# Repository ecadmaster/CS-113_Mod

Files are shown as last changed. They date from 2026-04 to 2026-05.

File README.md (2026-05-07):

# Modernización del Manipulador Robótico CS-113 / RS-2200 Pro-Arm

Este proyecto tiene como objetivo la recuperación y actualización tecnológica de los brazos robóticos CS-113 (RS-2200 Pro-Arm) pertenecientes a la [Universidad de Los Andes (ULA)](http://ula.ve/). Mediante el estudio del esquema original y la migración a herramientas modernas como [KiCad EDA](https://www.kicad.org/), se ha diseñado un método para interceptar el bus de control original y sustituir el microprocesador [Zilog Z80](https://www.zilog.com/docs/z80/um0080.pdf) por [microcontroladores](https://es.wikipedia.org/wiki/Microcontrolador)/[SoC](https://es.wikipedia.org/wiki/Sistema_en_un_chip) de nueva generación.

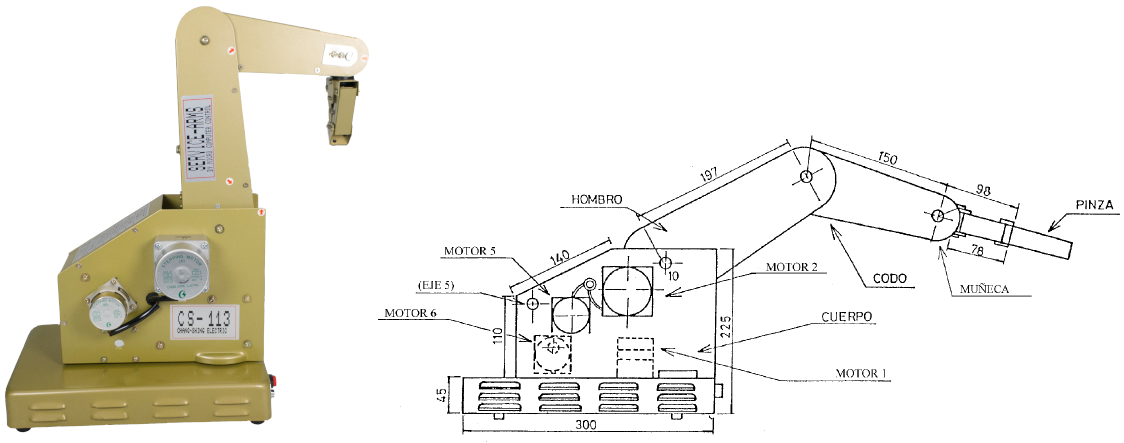
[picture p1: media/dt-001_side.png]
cs-113_side


## Descripción del Proyecto

Los manipuladores robóticos CS-113 fueron equipos estándar en laboratorios de robótica, pero su dependencia del [puerto paralelo (LPT)](https://es.wikipedia.org/wiki/Puerto_paralelo) y del microprocesador Z80 los hace difícilmente integrables en entornos actuales.

Este desarrollo propone:

- Ingeniería Inversa: Estudio del esquema original de la placa rotulada como DT-001.
- Migración CAD: Reconstrucción del esquema en KiCad EDA para facilitar el análisis de interconexiones.
- Intercepción de Bus: Remoción de los [ICs](https://es.wikipedia.org/wiki/Circuito_integrado) [Zilog Z80](https://www.zilog.com/docs/z80/um0080.pdf) ($$C4$$ renombrado como $$uC4$$) y [74LS04](https://www.ti.com/lit/ds/symlink/sn74ls04.pdf) ($$D7$$ renombrado como $$uD7$$) para inyectar señales de control desde un controlador externo.
- Control Moderno: Uso de una tarjeta [MikroElectronika EasyPIC6](https://www.microchip.com/en-us/development-tool/tmik003) actualizada con un microcontrolador [Microchip PIC18F46K40](https://www.microchip.com/en-us/product/pic18f46k40).

## Esquemas

La [placa base](https://es.wikipedia.org/wiki/Circuito_impreso) del manipulador se encuentra ubicada por la parte inferior del mismo.

### Esquema original

El circuito disponible en la pagina #13 del documento [RS-2200_Pro-Arm_Robotics](datasheet/RS-2200_Pro-Arm_Robotics.pdf), entre otros valores interesantes que se logran conseguir allí de éste aparato.

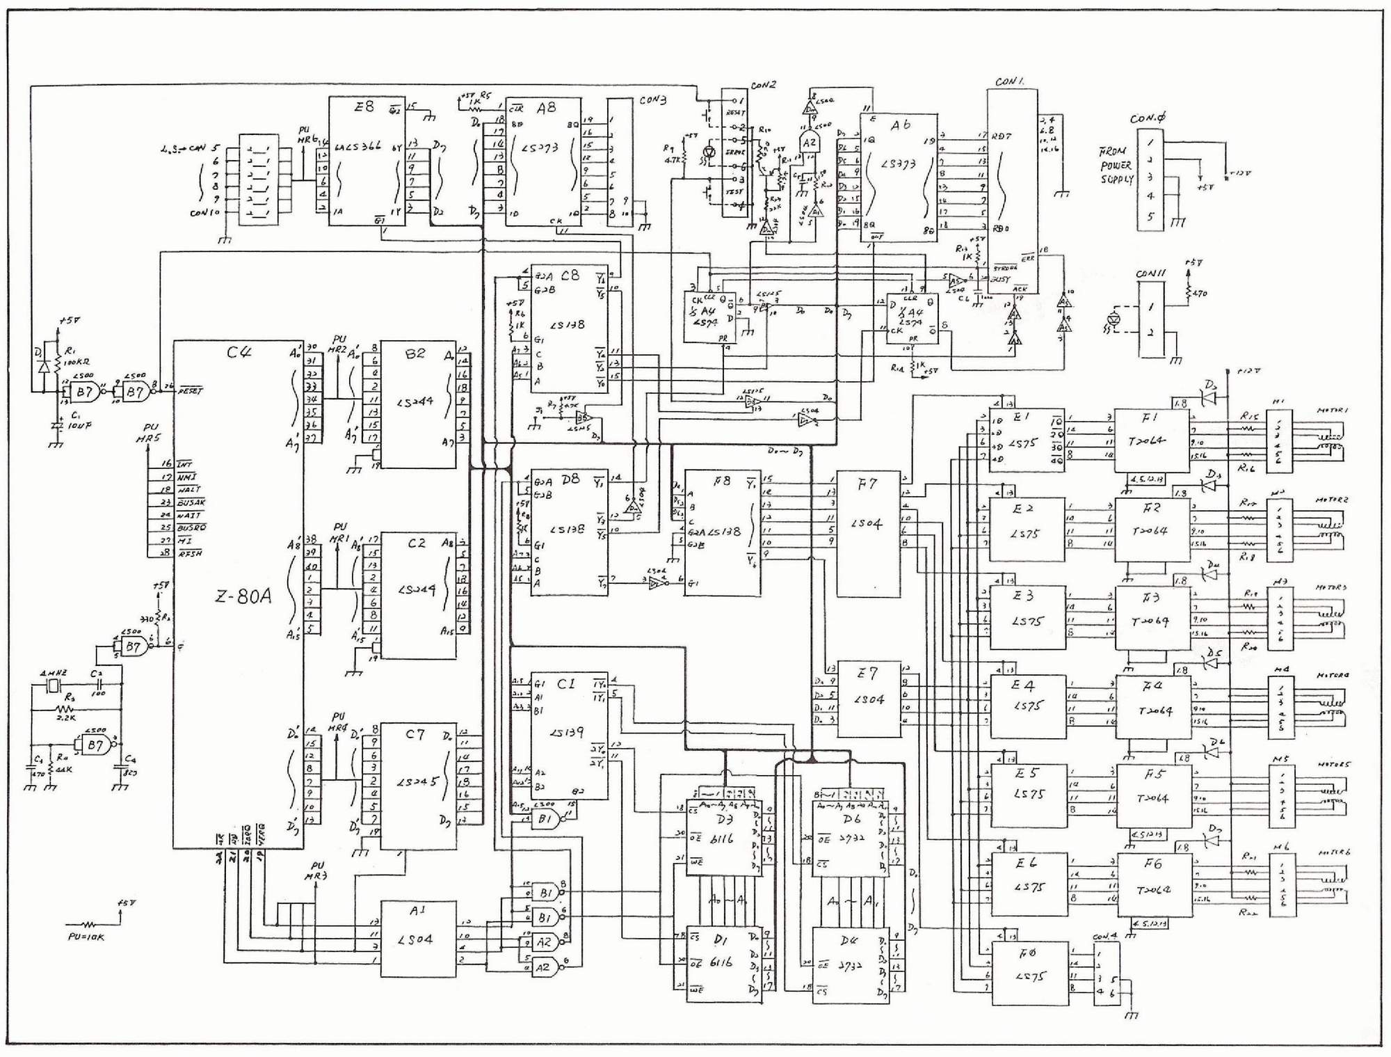
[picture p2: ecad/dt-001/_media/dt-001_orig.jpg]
dt-001-orig


### Esquema migrado a KiCad EDA

El esquema migrado a una herramienta de diseño es como sigue:

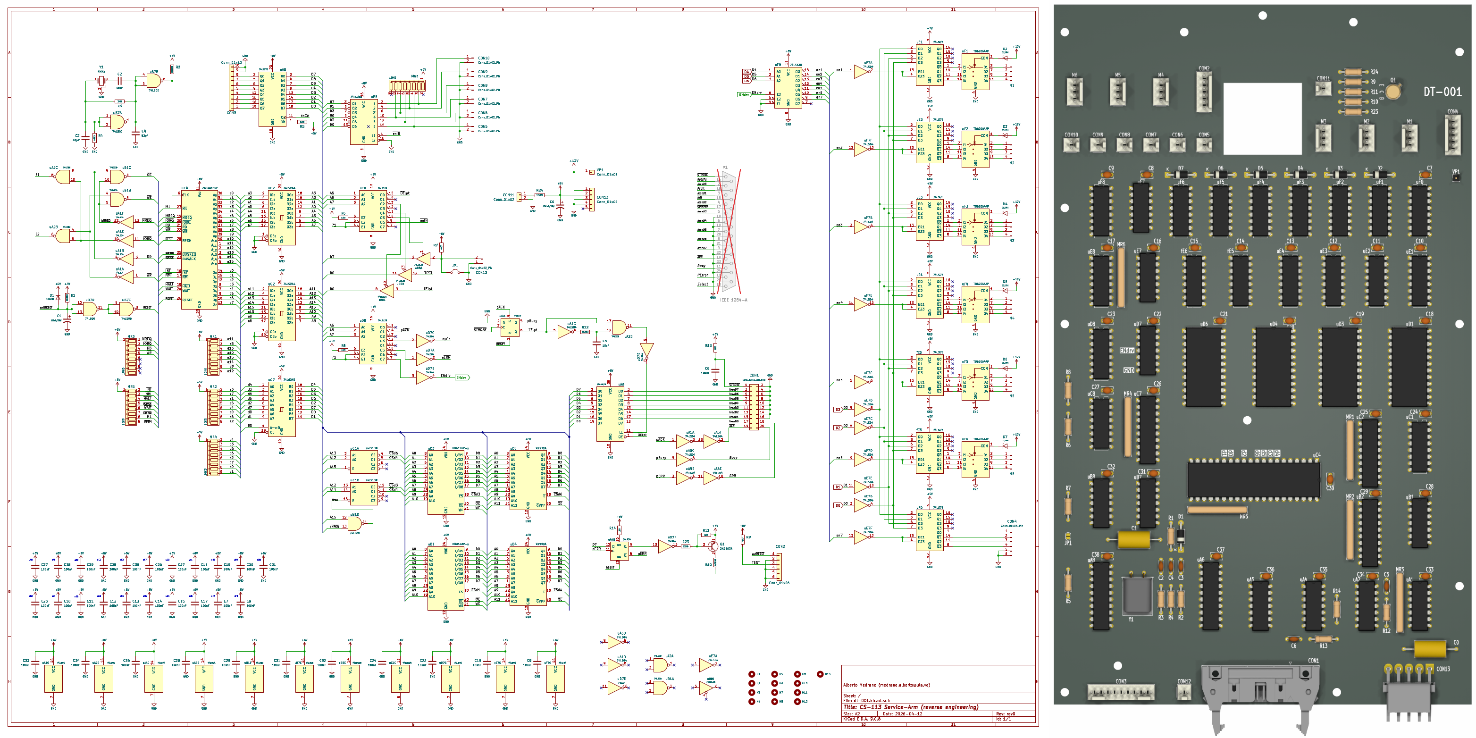
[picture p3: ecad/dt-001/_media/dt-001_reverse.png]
dt-001-kicad-sch


## Hardware y Modificaciones

### Componentes Reutilizados (Bloque de Potencia)

La placa original utiliza una arquitectura lógica robusta que se mantiene para el manejo de los motores, para ello se requiere la comprensión de los siguientes elementos:

- [74LS245](https://www.ti.com/lit/ds/symlink/sn74ls245.pdf): Transceptores de bus octales.
- [74LS138](https://www.ti.com/lit/ds/symlink/sn74ls138.pdf): Decodificador/demultiplexor de 3 a 8 líneas.
- [74LS75](https://www.ti.com/lit/ds/symlink/sn74ls75.pdf): Latches biestables de 4 bits.
- [TD62064AP](https://mm.digikey.com/Volume0/opasdata/d220001/medias/docus/932/TD62064AP%2CAF.pdf): Drivers [Darlington](https://es.wikipedia.org/wiki/Transistor_Darlington) de alta corriente para los [motores paso a paso (Stepper)](https://es.wikipedia.org/wiki/Motor_paso_a_paso) de tipo unipolar.

Una vez consolidado ese estudio y analizando la etapa de potencia, prácticamente solo se requiere el uso de lo siguiente:

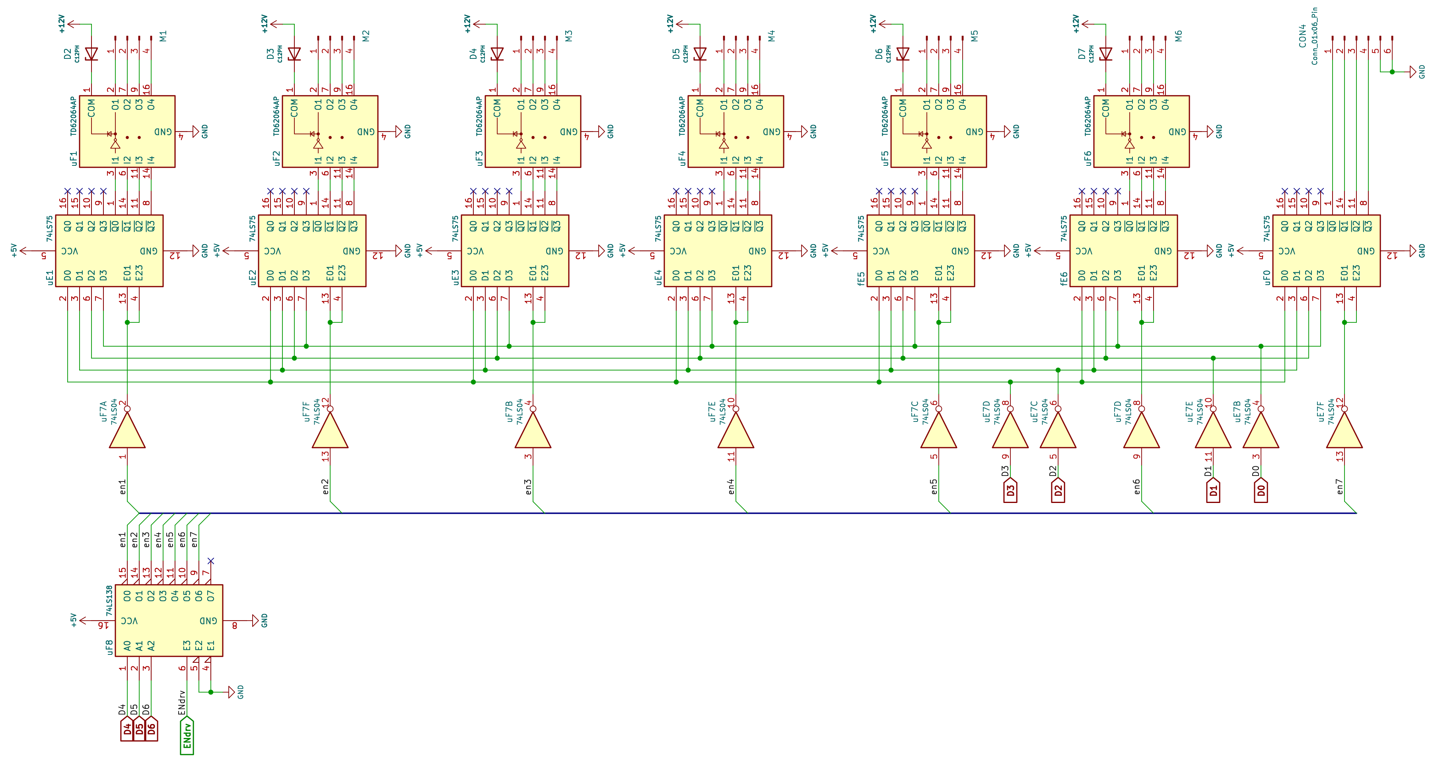
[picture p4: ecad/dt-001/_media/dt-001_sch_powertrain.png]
dt-001_sch_powertrain


Lo anterior sugiere que los IC: $$uC7$$, $$uE1$$, $$uE2$$, $$uE3$$, $$uE4$$, $$uE5$$, $$uE6$$, $$uE7$$, $$uF0$$, $$uF1$$, $$uF2$$, $$uF3$$, $$uF4$$, $$uF5$$, $$uF6$$, $$uF7$$ y $$uF8$$ deban estar debidamente colocados.

Tambien es requerido remover los ICs: $$uA6$$, $$uA8$$, $$uB8$$, $$uC4$$(Z80), $$uD1$$, $$uD3$$, $$uD4$$, $$uD6$$ y $$uD7$$ y $$uD7$$ para no interferir con las señales externas que provengan del controlador externo.

### Interfaz de Conexión (DB9 Personalizado)

Se ha implementado una conexión mediante un conector DB9 macho para el control de los 6 motores de paso y funciones adicionales:

| DB9 Macho | Etiqueta | Conexión |
| :--- | :--- | :--- |
| Pin 1	| d0 | $$uC4$$ pin #14 |
| Pin 2	| d1 | $$uC4$$ pin #15 |
| Pin 3	| d2 | $$uC4$$ pin #12 |
| Pin 4	| d3 | $$uC4$$ pin #8 |
| Pin 5	| d4 | $$uC4$$ pin #7 |
| Pin 6	| d5 | $$uC4$$ pin #9 |
| Pin 7	| d6 | $$uC4$$ pin #10 |
| Pin 8	| ENdrv | $$uD7$$ pin #4 |
| Pin 9	| GND | $$uD7$$ pin #7 |

Quedando la modificación como sigue:

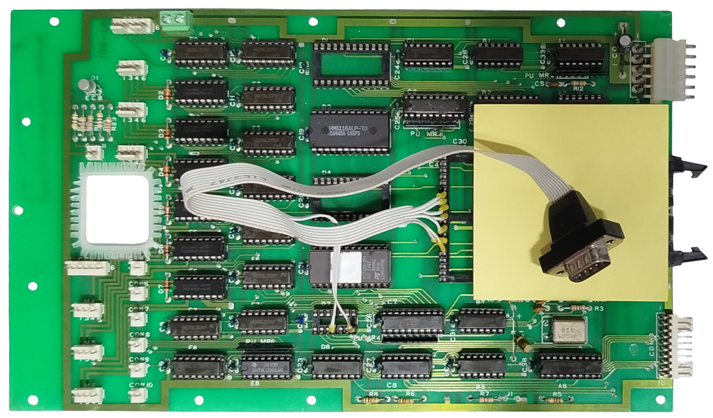
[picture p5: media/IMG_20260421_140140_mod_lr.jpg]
IMG_20260421_140140_mod_lr


Una propuesta de adaptación en la parte trasera es como sigue:

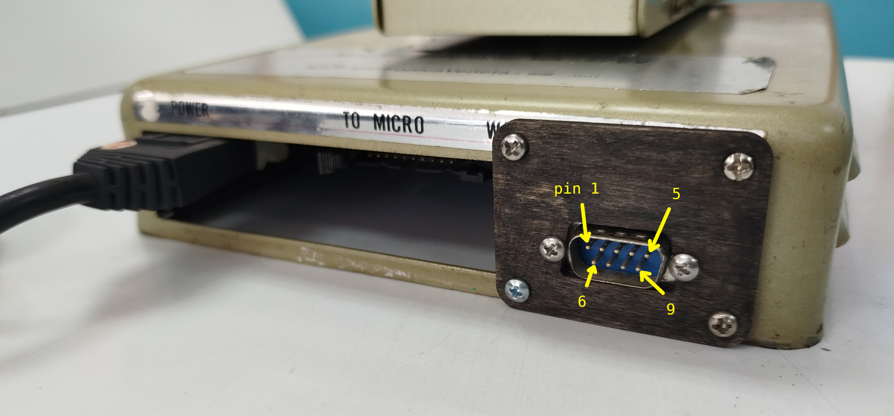
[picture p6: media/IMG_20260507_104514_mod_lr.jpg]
IMG_20260507_104514_mod_lr


El circuito que maneja el tren de potencia funciona con 5V TTL dado que todas las señales son de tipo entrada. Pueden conectarse controladores que funcionen a 3.3V directo sin necesidad de circuitos de interfaz, considere revisar los voltajes admitidos, ver [Logic Guide](https://www.ti.com/lit/sg/sdyu001ab/sdyu001ab.pdf) (de Texas Instruments) para mayor detalle y videoclase [Circuitos Interfaz](https://youtu.be/W1FWi5FtGR8).

## Desarrollo de Software

El firmware actual está siendo desarrollado para el [PIC18F46K40](https://www.microchip.com/en-us/product/pic18f46k40) utilizando:

- [MPLAB X IDE](https://www.microchip.com/en-us/tools-resources/develop/mplab-x-ide) con compilador [XC8](https://www.microchip.com/en-us/tools-resources/develop/mplab-xc-compilers/xc8).
- [MPLAB Code Configurator (MCC)](https://www.microchip.com/en-us/tools-resources/configure/mplab-code-configurator) para la configuración de periféricos.
- Capacidad de operación autónoma, asistida o vía [USB](https://es.wikipedia.org/wiki/Universal_Serial_Bus).

## Enlaces de Interés y Referencias

Proyectos y documentación relacionada que han servido de base:

- [Repositorio Digital ULA, Diseño e implementación de tarjeta de control para un brazo robotico CS-113, que se controle via USB](http://bdigital2.ula.ve:8080/xmlui/handle/654321/11944)
- [Análisis Técnico ITC](https://itc.ktu.lt/index.php/ITC/article/view/985/1054)
- [Hilo en Arduino Forum - Reconstrucción CS-113](https://forum.arduino.cc/t/reconstruccion-de-robot-cs-113/483691)
- [CS-113 Service-Arm](https://openvrg.moodlehub.com/file.php/30/cyr_0204/cyr_01/robotica/cs113.htm)
- [Hackaday.io - Robot Arm CS-113 Project](https://hackaday.io/project/168093-robot-arm-cs-113-18f4550-pic-usb-pc-controller)

Nota: Si has realizado algún intento de desarrollo con este manipulador, te invitamos a colaborar agregando tu referencia en esta sección.

## Colaboradores
- [Alberto Medrano](https://github.com/ecadmaster/)
- Francisco Viloria
- Gerardo Rueda
- Luis Araujo

## Instalación y Uso

Clona el repositorio:

```git clone https://github.com/ecadmaster/CS-113_Mod.git```

Consulta las datasheets para entender los límites operativos de los integrados.

## Contribuciones y Licencia
Este proyecto está bajo la licencia MIT. Las sugerencias de mejora para el entorno académico de la Escuela de Ingeniería Eléctrica son bienvenidas.

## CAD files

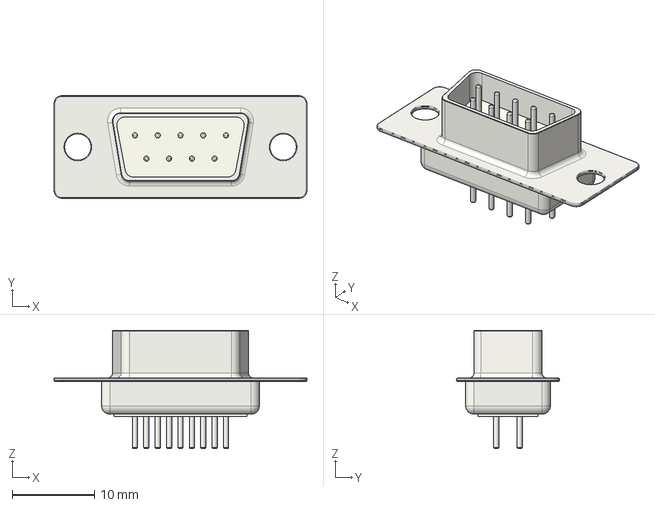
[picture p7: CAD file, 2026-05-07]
panel/DSUB-9_Pins_Vertical_P2.77x2.84mm.step
30.8 x 12.5 x 14.4 mm

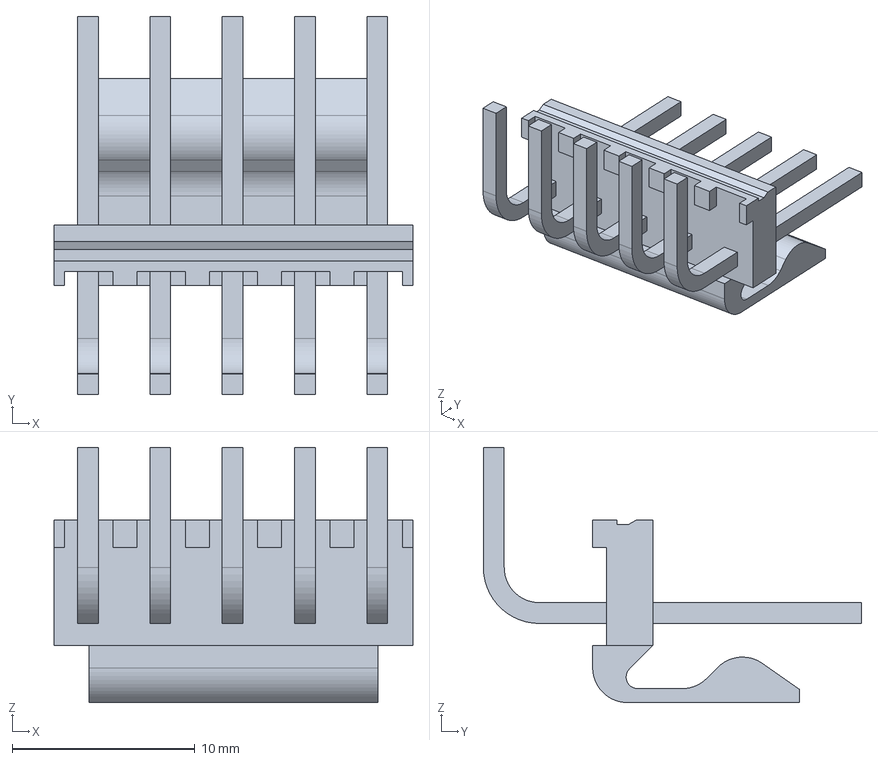
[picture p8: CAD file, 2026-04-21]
ecad/dt-001/_local/Molex_KK-396_26605050_1x05_P3.96mm_Horizontal.step
19.7 x 20.7 x 14.0 mm

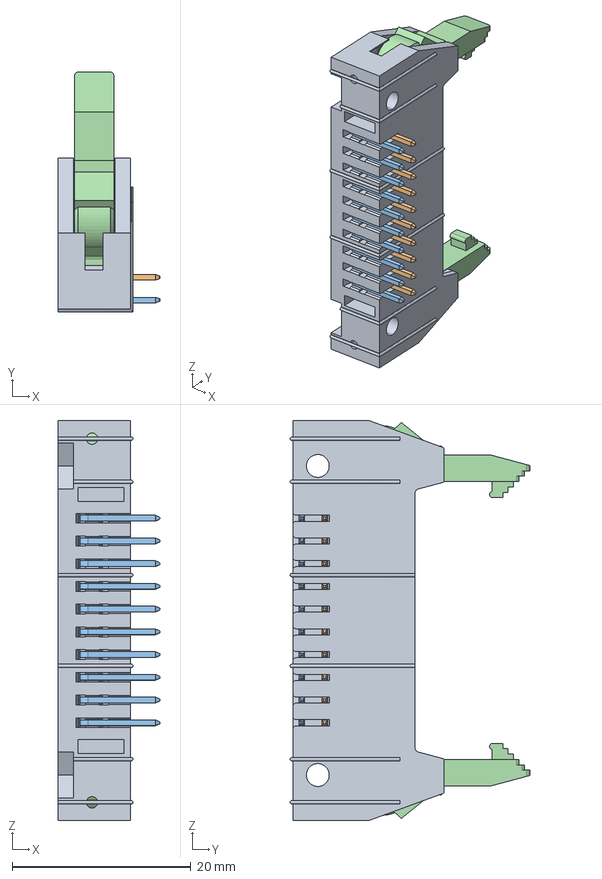
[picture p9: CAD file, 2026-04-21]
ecad/dt-001/_local/71922-120LF.step
11.4 x 26.8 x 44.7 mm
67017_Y20
77391_Y21 x 10
77391_Y25 x 10

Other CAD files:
panel/addon_db9.FCStd

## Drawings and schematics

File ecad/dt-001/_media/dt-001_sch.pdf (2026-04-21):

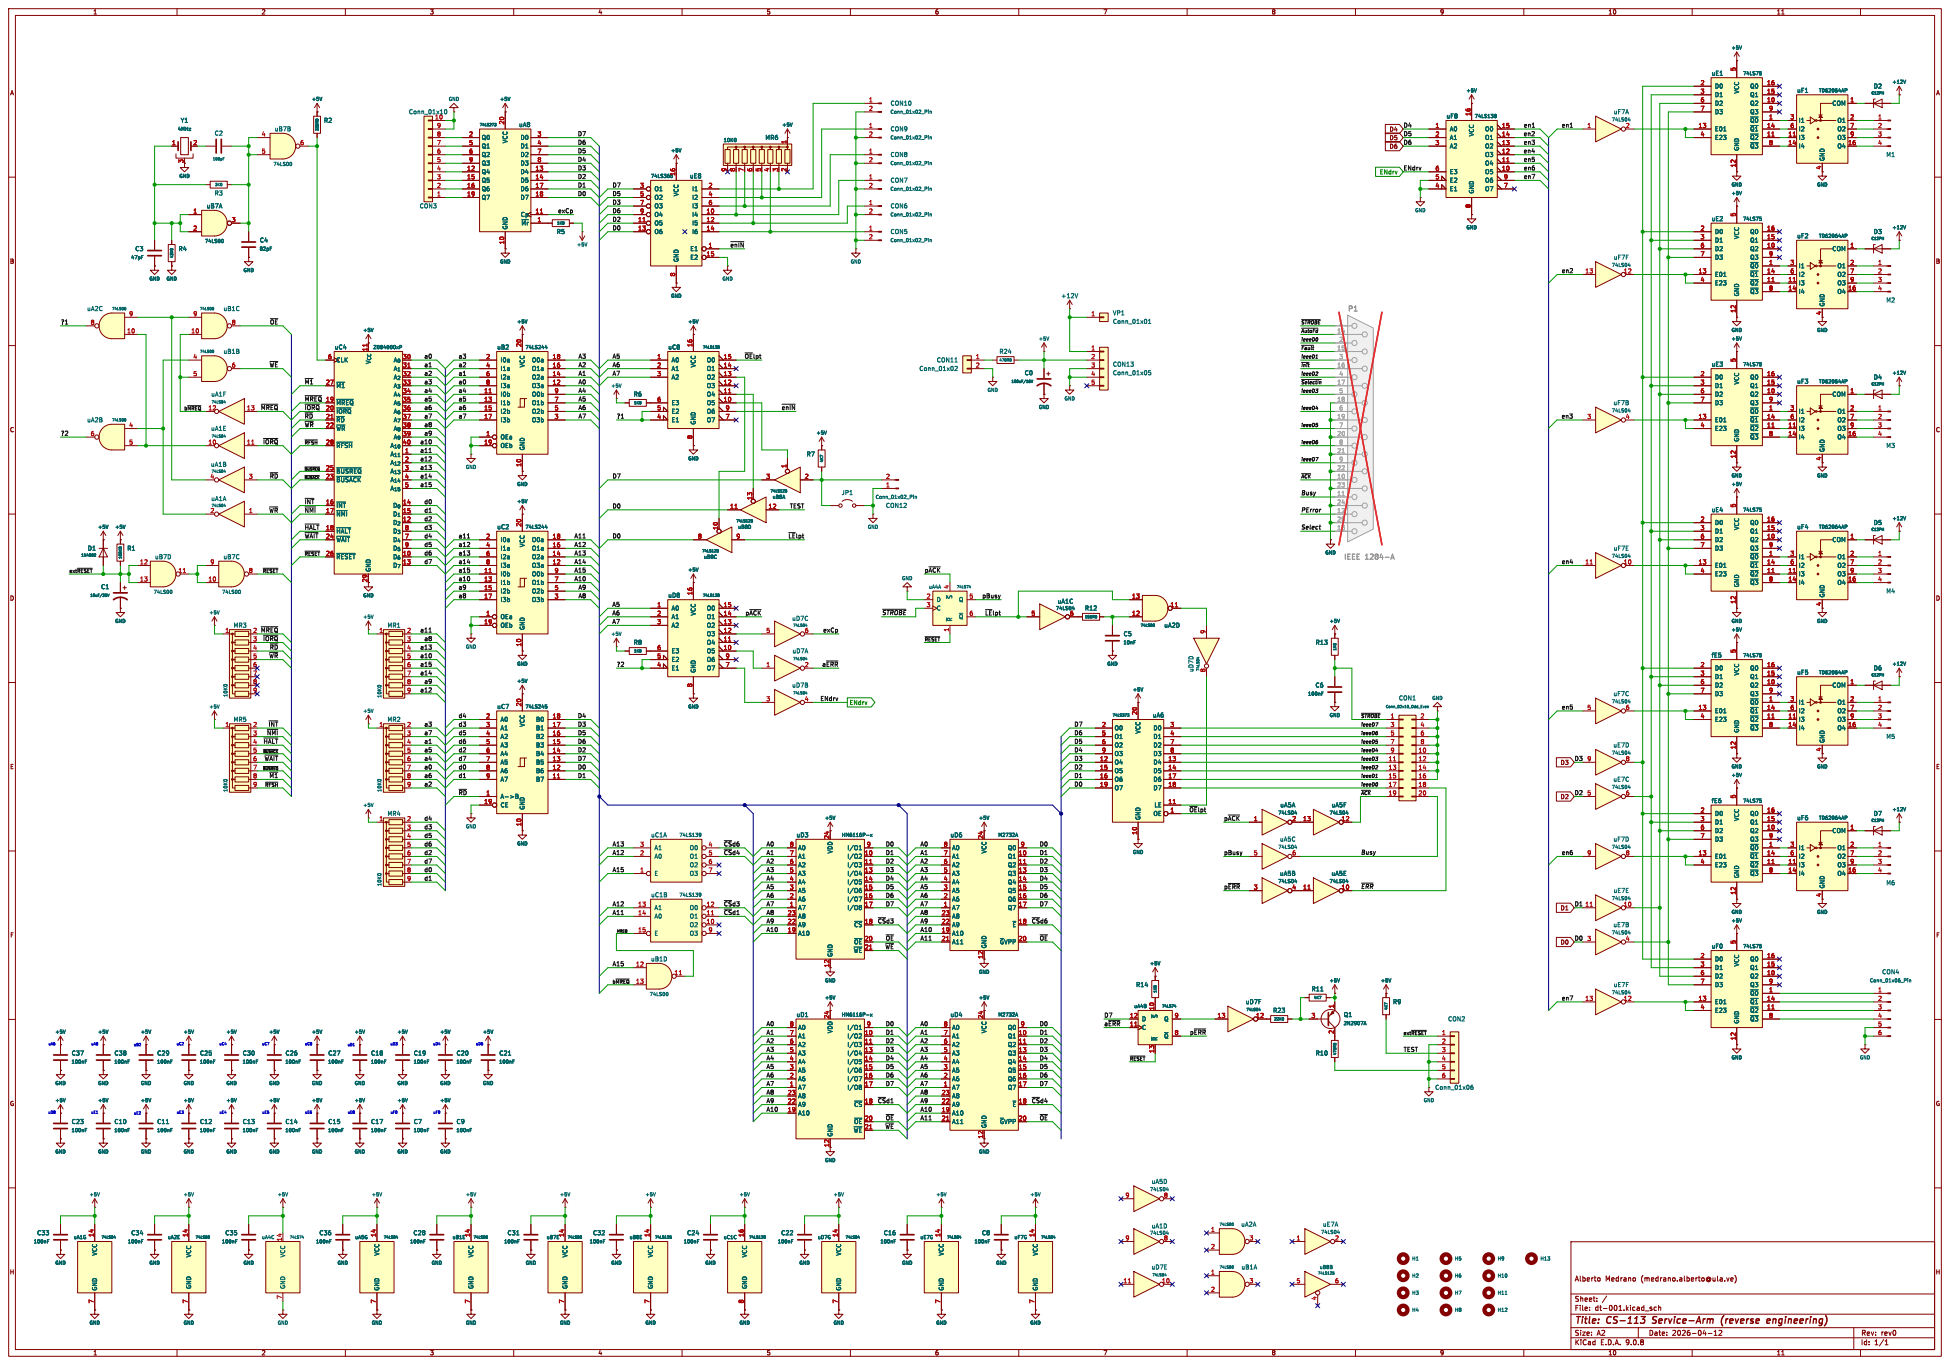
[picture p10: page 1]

p~{ACK} ENdrv ~{LE}lpt

I/O8 17 ~{CS} 18 ~{OE} 20 ~{WE} 21 GND

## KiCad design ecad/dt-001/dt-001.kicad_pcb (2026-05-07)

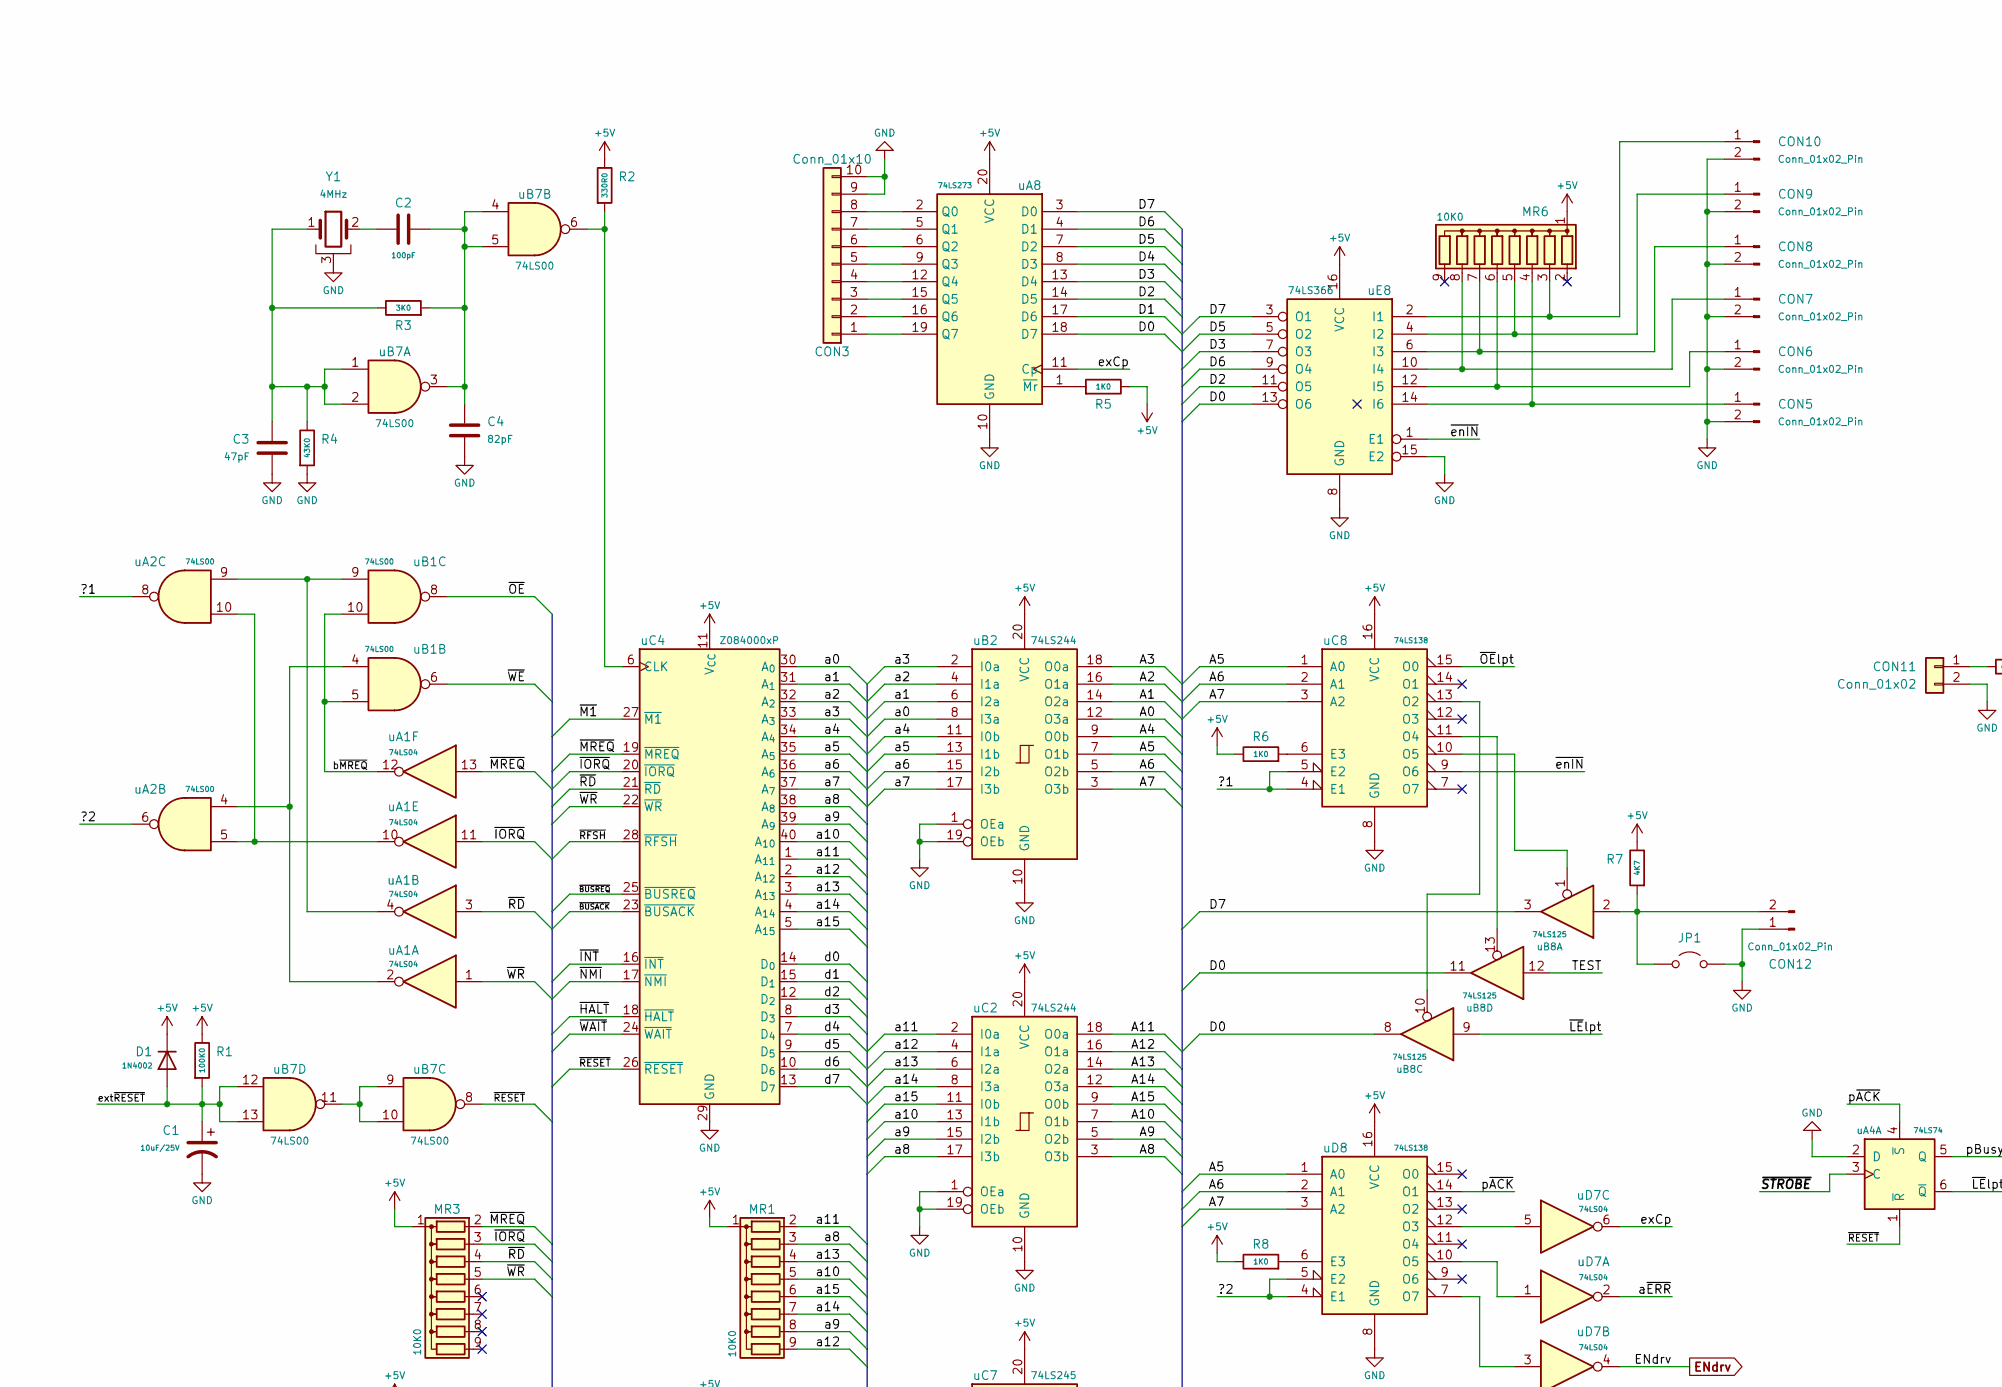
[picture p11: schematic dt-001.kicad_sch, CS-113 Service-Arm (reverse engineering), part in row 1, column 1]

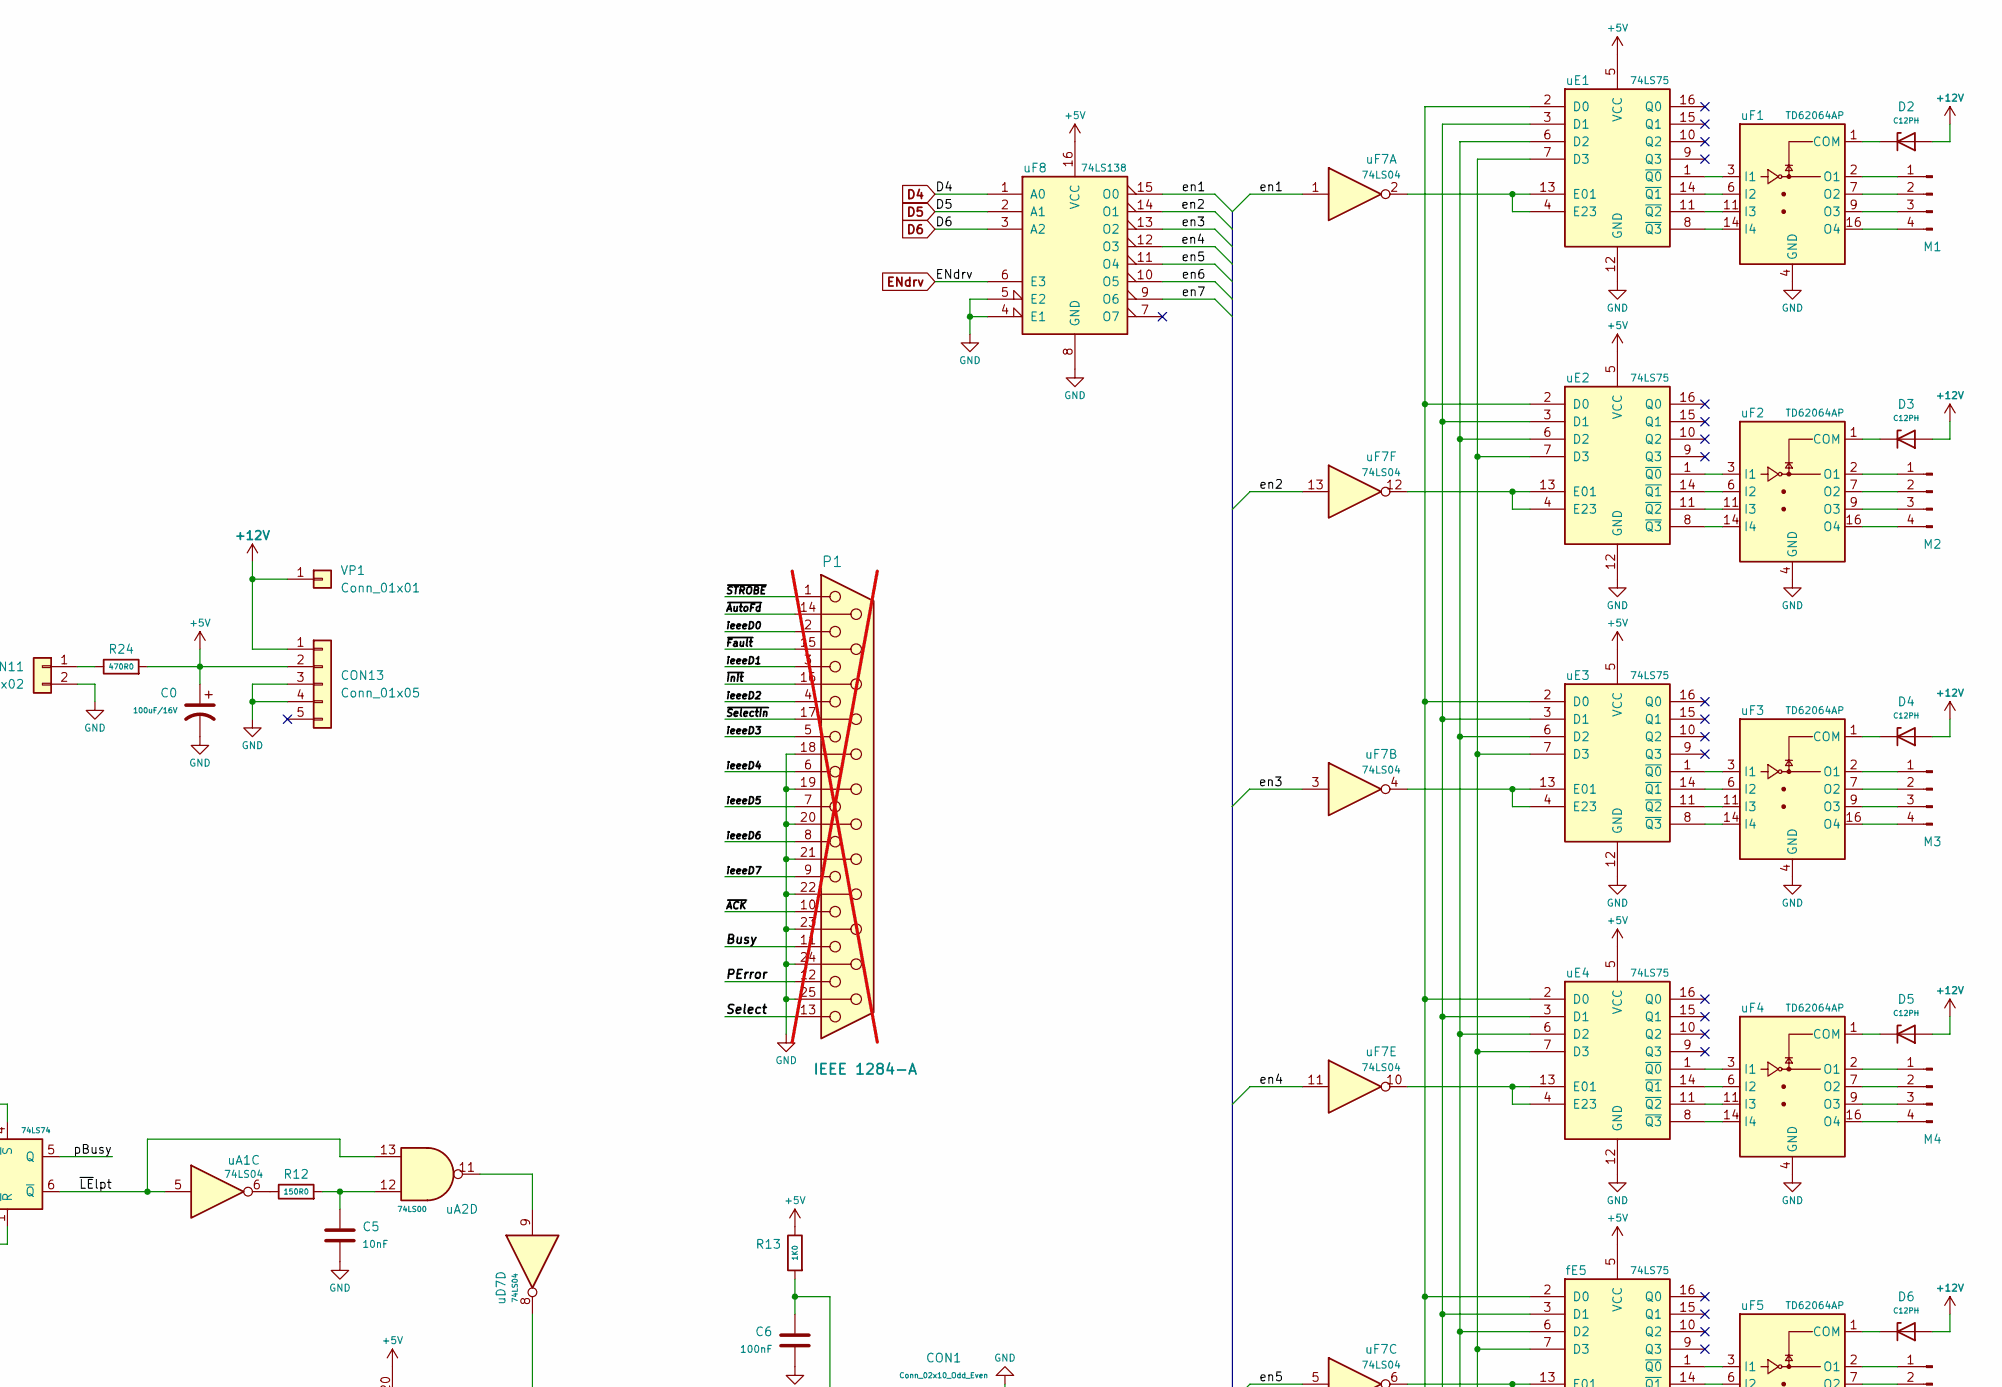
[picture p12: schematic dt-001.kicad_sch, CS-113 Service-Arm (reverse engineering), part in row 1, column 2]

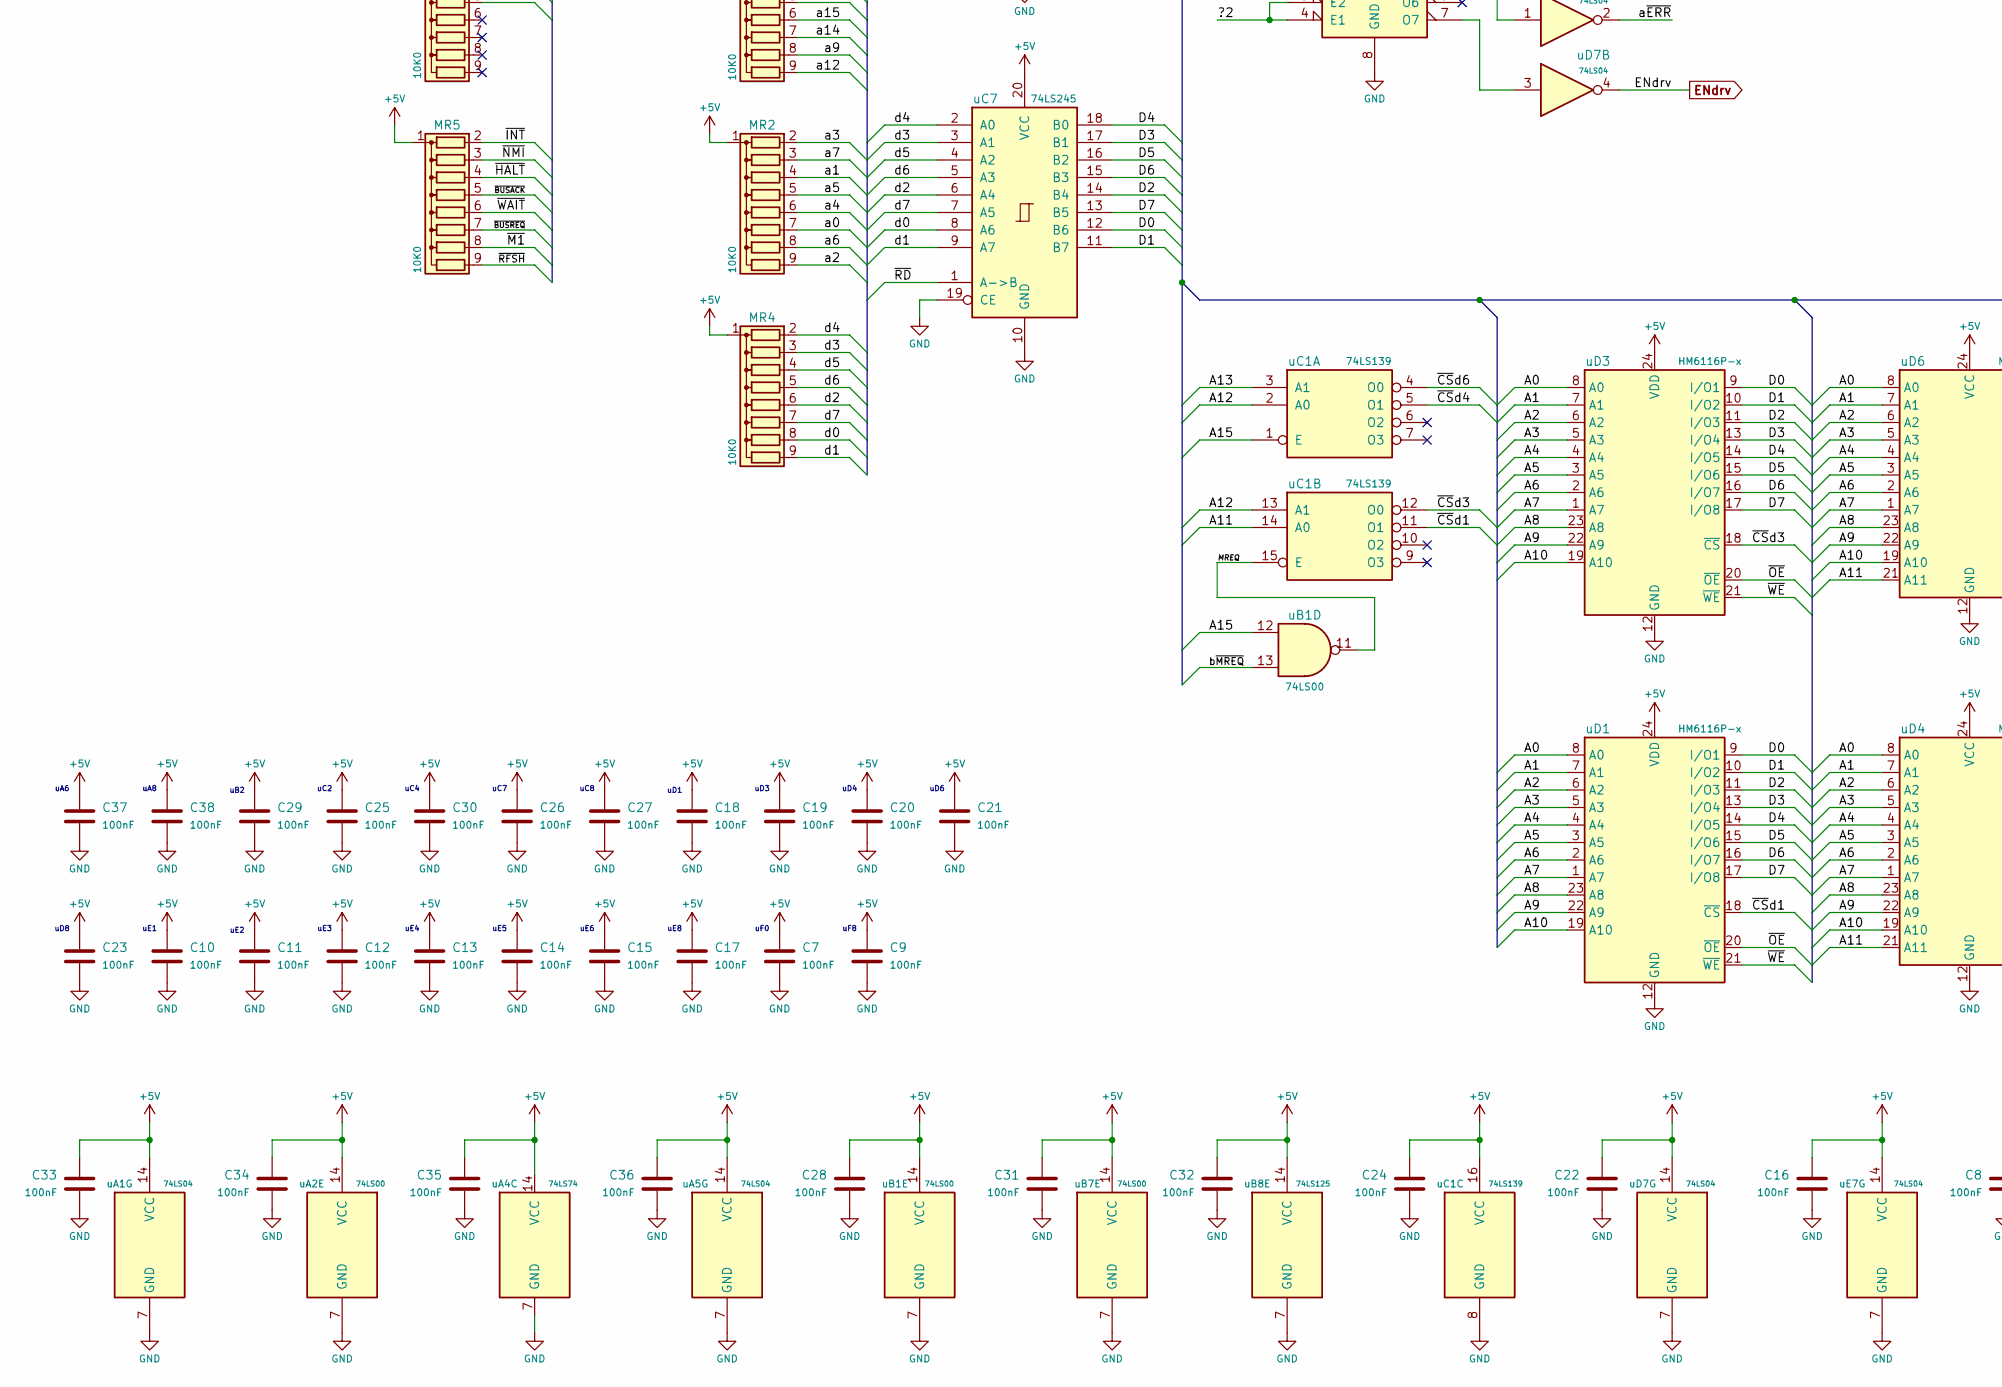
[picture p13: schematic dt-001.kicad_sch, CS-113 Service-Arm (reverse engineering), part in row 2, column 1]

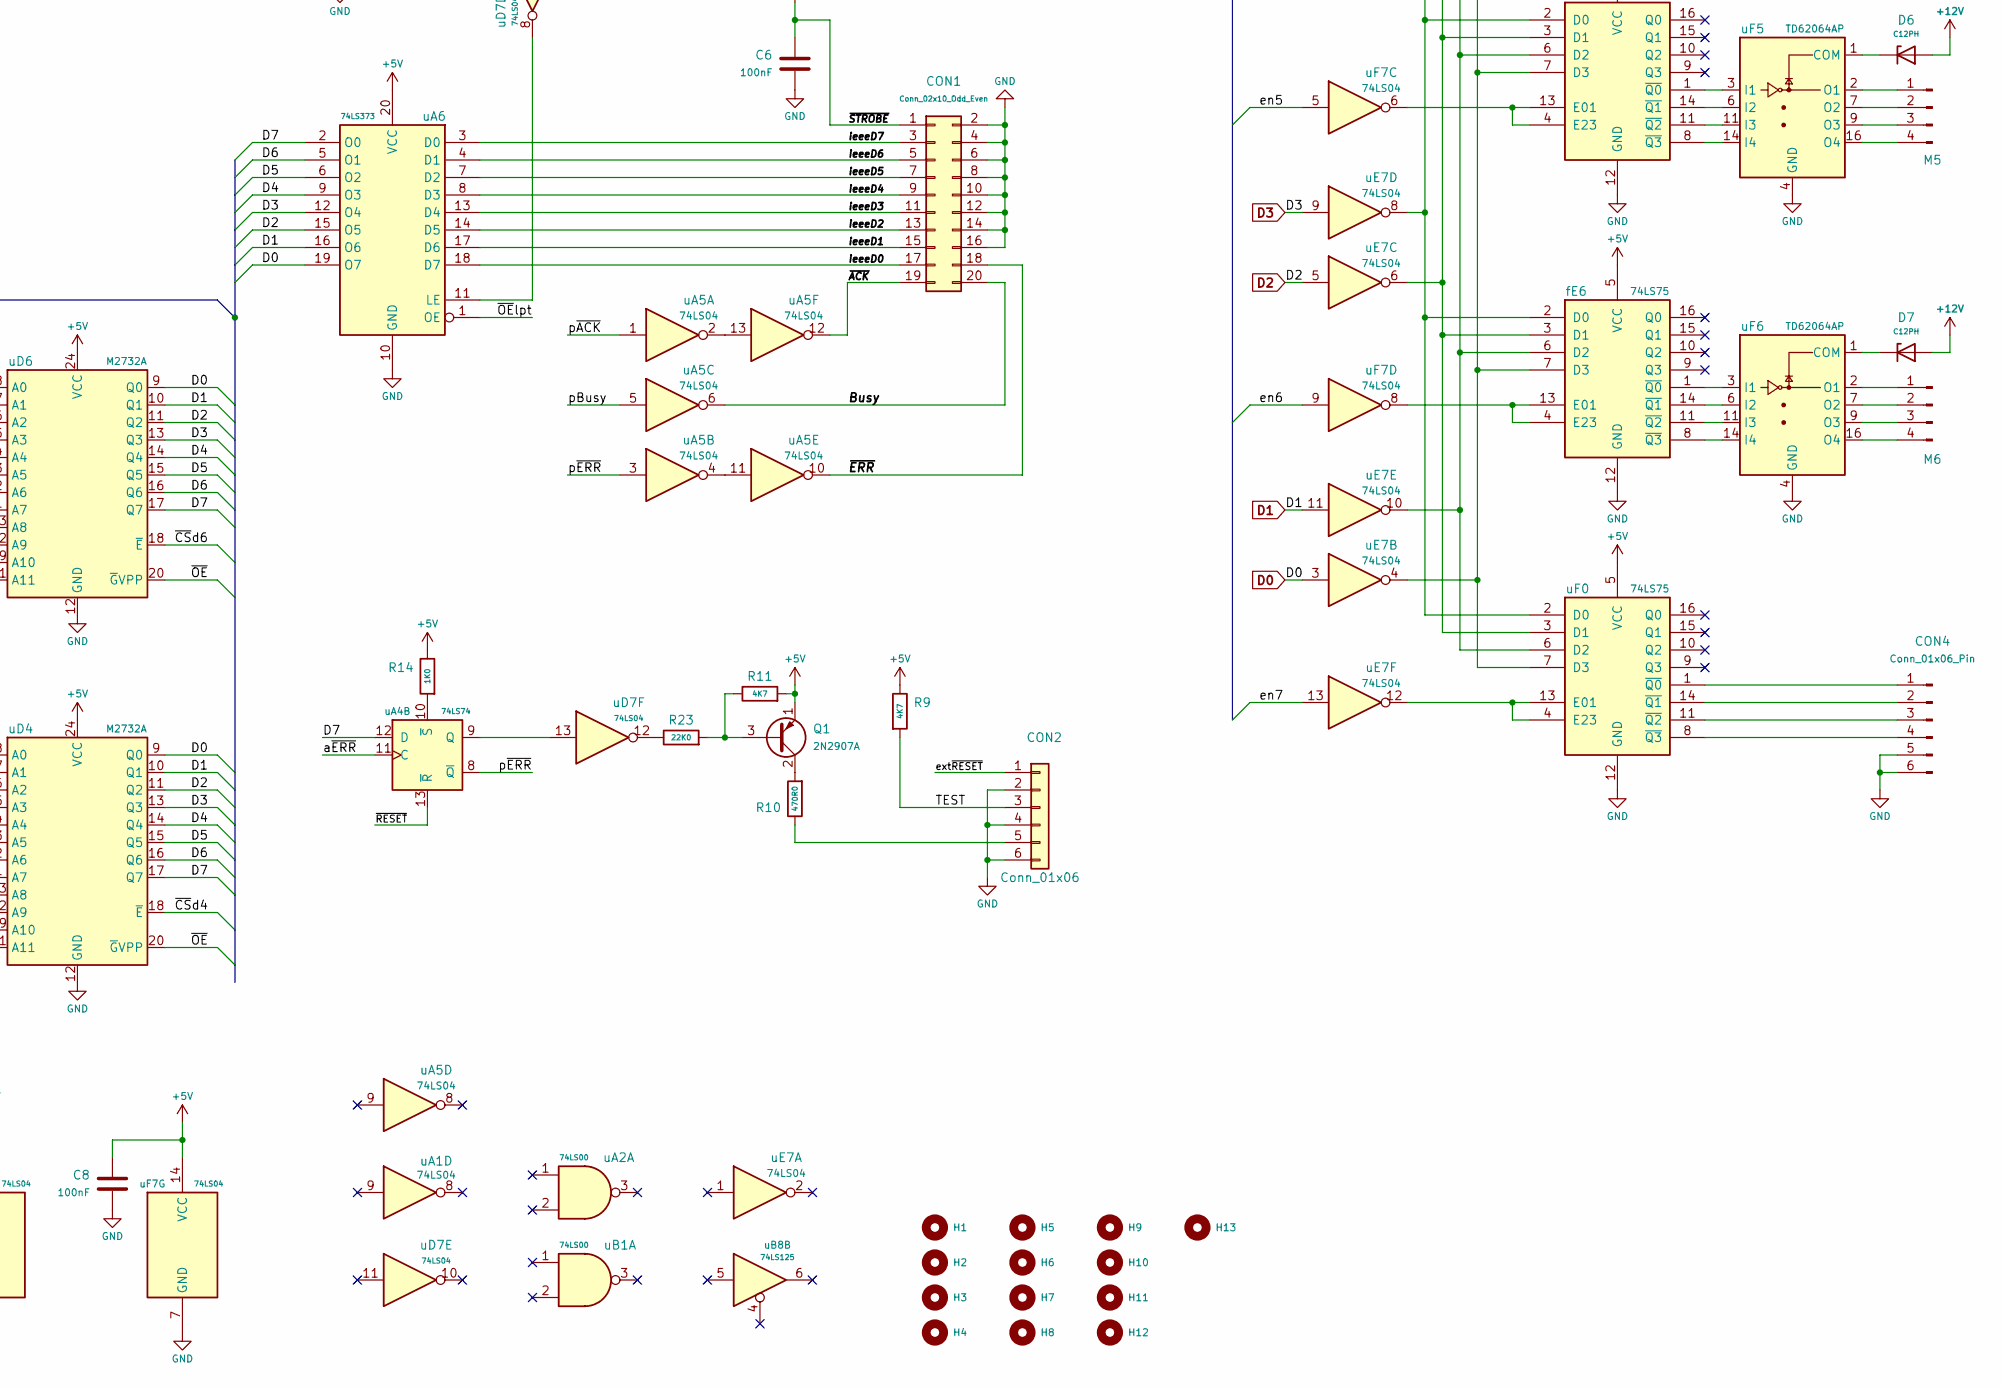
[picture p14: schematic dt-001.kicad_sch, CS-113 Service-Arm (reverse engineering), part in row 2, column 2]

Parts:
C0: 100uF/16V; C_Axial_L12.0mm_D6.5mm_P20.00mm_Horizontal
C1: 10uF/25V; C_Axial_L12.0mm_D6.5mm_P20.00mm_Horizontal
C2: 100pF; C_Disc_D4.3mm_W1.9mm_P5.00mm
C3: 47pF; C_Disc_D4.3mm_W1.9mm_P5.00mm
C4: 82pF; C_Disc_D4.3mm_W1.9mm_P5.00mm
C5: 10nF; C_Disc_D4.3mm_W1.9mm_P5.00mm
C6: 100nF; C_Disc_D4.3mm_W1.9mm_P5.00mm
C7, C8, C9, C10, C11, C12, C13, C14, C15, C16, C17, C18, C19, C20, C21, C22, C23, C24, C25, C26, C27, C28, C29, C30, C31, C32, C33, C34, C35, C36, C37, C38: 100nF; C_Disc_D3.8mm_W2.6mm_P3.175mm
CON1: Conn_02x10_Odd_Even; 71922-120LF
CON2: Conn_01x06; Molex_KK-254_AE-6410-06A_1x06_P2.54mm_Vertical
CON3: Conn_01x10; Molex_KK-254_AE-6410-10A_1x10_P2.54mm_Vertical
CON4: Conn_01x06_Pin; Molex_KK-254_AE-6410-06A_1x06_P2.54mm_Vertical
CON5, CON6, CON7, CON8, CON9, CON10, CON12: Conn_01x02_Pin; Molex_KK-254_AE-6410-02A_1x02_P2.54mm_Vertical
CON11: Conn_01x02; Molex_KK-254_AE-6410-02A_1x02_P2.54mm_Vertical
CON13: Conn_01x05; Molex_KK-396_26605050_1x05_P3.96mm_Horizontal
D1: 1N4002; D_DO-41_SOD81_P10.16mm_Horizontal
D2, D3, D4, D5, D6, D7: C12PH; D_DO-41_SOD81_P10.16mm_Horizontal
H1, H2, H3, H4, H5, H6, H7, H8, H9, H10, H11, H12, H13: MountingHole; MountingHole_3.2mm_M3
JP1: Jumper_2_Open; SolderJumper-2_P1.3mm_Open_RoundedPad1.0x1.5mm
M1, M2, M3, M4, M5, M6: Conn_01x04_Pin; Molex_KK-254_AE-6410-04A_1x04_P2.54mm_Vertical
MR1, MR2, MR3, MR4, MR5, MR6: 10K0; R_Array_SIP9
P1: IEEE 1284-A; not fitted
Q1: 2N2907A; TO-18-3
R1: 100K0; R_Axial_DIN0207_L6.3mm_D2.5mm_P10.16mm_Horizontal
R2: 330R0; R_Axial_DIN0207_L6.3mm_D2.5mm_P10.16mm_Horizontal
R3: 3K0; R_Axial_DIN0207_L6.3mm_D2.5mm_P10.16mm_Horizontal
R4: 43K0; R_Axial_DIN0207_L6.3mm_D2.5mm_P10.16mm_Horizontal
R5, R6, R8, R13, R14: 1K0; R_Axial_DIN0207_L6.3mm_D2.5mm_P10.16mm_Horizontal
R7, R9, R11: 4K7; R_Axial_DIN0207_L6.3mm_D2.5mm_P10.16mm_Horizontal
R10, R24: 470R0; R_Axial_DIN0207_L6.3mm_D2.5mm_P10.16mm_Horizontal
R12: 150R0; R_Axial_DIN0207_L6.3mm_D2.5mm_P10.16mm_Horizontal
R23: 22K0; R_Axial_DIN0207_L6.3mm_D2.5mm_P10.16mm_Horizontal
VP1: Conn_01x01; PinHeader_1x01_P2.54mm_Vertical
Y1: 4MHz; Crystal_HC49-U_Horizontal_1EP_style1
fE5, fE6: 74LS75; DIP-16_W7.62mm
uA1, uA5: 74LS04; DIP-14_W7.62mm
uA2: 74LS00; DIP-14_W7.62mm
uA4: 74LS74; DIP-14_W7.62mm
uA6: 74LS373; DIP-20_W7.62mm
uA8: 74LS273; DIP-20_W7.62mm
uB1, uB7: 74LS00; DIP-14_W7.62mm
uB2: 74LS244; DIP-20_W7.62mm
uB8: 74LS125; DIP-14_W7.62mm
uC1: 74LS139; DIP-16_W7.62mm
uC2: 74LS244; DIP-20_W7.62mm
uC4: Z084000xP; DIP-40_W15.24mm
uC7: 74LS245; DIP-20_W7.62mm
uC8: 74LS138; DIP-16_W7.62mm
uD1, uD3: HM6116P-x; DIP-24_W15.24mm
uD4, uD6: M2732A; DIP-24_W15.24mm
uD7: 74LS04; DIP-14_W7.62mm
uD8: 74LS138; DIP-16_W7.62mm
uE1, uE2, uE3, uE4: 74LS75; DIP-16_W7.62mm
uE7: 74LS04; DIP-14_W7.62mm
uE8: 74LS366; DIP-16_W7.62mm
uF0: 74LS75; DIP-16_W7.62mm
uF1, uF2, uF3, uF4, uF5, uF6: TD62064AP; DIP-16_W7.62mm
uF7: 74LS04; DIP-14_W7.62mm
uF8: 74LS138; DIP-16_W7.62mm

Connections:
+5V: C0.1, C7.1, C8.1, C9.1, C10.1, C11.1, C12.1, C13.1, C14.1, C15.1, C16.1, C17.1, C18.1, C19.1, C20.1, C21.1, C22.1, C23.1, C24.1, C25.1, C26.1, C27.1, C28.1, C29.1, C30.1, C31.1, C32.1, C33.1, C34.1, C35.1, C36.1, C37.1, C38.1, CON13.2, D1.1 (K), MR1.1 (common), MR2.1 (common), MR3.1 (common), MR4.1 (common), MR5.1 (common), MR6.1 (common), Q1.1 (E), R1.1, R2.1, R5.1, R6.1, R7.1, R8.1, R9.1, R11.2, R13.1, R14.1, R24.2, fE5.5 (VCC), fE6.5 (VCC), uA1.14 (VCC), uA2.14 (VCC), uA4.14 (VCC), uA5.14 (VCC), uA6.20 (VCC), uA8.20 (VCC), uB1.14 (VCC), uB2.20 (VCC), uB7.14 (VCC), uB8.14 (VCC), uC1.16 (VCC), uC2.20 (VCC), uC4.11 (V_{CC}), uC7.20 (VCC), uC8.16 (VCC), uD1.24 (VDD), uD3.24 (VDD), uD4.24 (VCC), uD6.24 (VCC), uD7.14 (VCC), uD8.16 (VCC), uE1.5 (VCC), uE2.5 (VCC), uE3.5 (VCC), uE4.5 (VCC), uE7.14 (VCC), uE8.16 (VCC), uF0.5 (VCC), uF7.14 (VCC), uF8.16 (VCC)
+12V: CON13.1, D2.2 (A), D3.2 (A), D4.2 (A), D5.2 (A), D6.2 (A), D7.2 (A), VP1.1 (Pin_1_1)
/?1: uA2.8, uC8.4 (E1), uC8.5 (E2)
/?2: uA2.6, uD8.4 (E1), uD8.5 (E2)
/A0: uB2.12 (O3a), uD1.8 (A0), uD3.8 (A0), uD4.8 (A0), uD6.8 (A0)
/A1: uB2.14 (O2a), uD1.7 (A1), uD3.7 (A1), uD4.7 (A1), uD6.7 (A1)
/A2: uB2.16 (O1a), uD1.6 (A2), uD3.6 (A2), uD4.6 (A2), uD6.6 (A2)
/A3: uB2.18 (O0a), uD1.5 (A3), uD3.5 (A3), uD4.5 (A3), uD6.5 (A3)
/A4: uB2.9 (O0b), uD1.4 (A4), uD3.4 (A4), uD4.4 (A4), uD6.4 (A4)
/A5: uB2.7 (O1b), uC8.1 (A0), uD1.3 (A5), uD3.3 (A5), uD4.3 (A5), uD6.3 (A5), uD8.1 (A0)
/A6: uB2.5 (O2b), uC8.2 (A1), uD1.2 (A6), uD3.2 (A6), uD4.2 (A6), uD6.2 (A6), uD8.2 (A1)
/A7: uB2.3 (O3b), uC8.3 (A2), uD1.1 (A7), uD3.1 (A7), uD4.1 (A7), uD6.1 (A7), uD8.3 (A2)
/A8: uC2.3 (O3b), uD1.23 (A8), uD3.23 (A8), uD4.23 (A8), uD6.23 (A8)
/A9: uC2.5 (O2b), uD1.22 (A9), uD3.22 (A9), uD4.22 (A9), uD6.22 (A9)
/A10: uC2.7 (O1b), uD1.19 (A10), uD3.19 (A10), uD4.19 (A10), uD6.19 (A10)
/A11: uC1.14 (A0), uC2.18 (O0a), uD4.21 (A11), uD6.21 (A11)
/A12: uC1.2 (A0), uC1.13 (A1), uC2.16 (O1a)
/A13: uC1.3 (A1), uC2.14 (O2a)
/A14: uC2.12 (O3a)
/A15: uB1.12, uC1.1 (E), uC2.9 (O0b)
/Busy: CON1.20, P1.11, uA5.6
/D7: uA4.12 (D), uA6.2 (O0), uA8.3 (D0), uB8.3, uC7.13 (B5), uD1.17 (I/O8), uD3.17 (I/O8), uD4.17 (Q7), uD6.17 (Q7), uE8.3 (O1)
/MREQ: uB1.11, uC1.15 (E)
/TEST: CON2.3, R9.2, uB8.12
/a0: MR2.7 (R6), uB2.8 (I3a), uC4.30 (A_{0})
/a1: MR2.4 (R3), uB2.6 (I2a), uC4.31 (A_{1})
/a2: MR2.9 (R8), uB2.4 (I1a), uC4.32 (A_{2})
/a3: MR2.2 (R1), uB2.2 (I0a), uC4.33 (A_{3})
/a4: MR2.6 (R5), uB2.11 (I0b), uC4.34 (A_{4})
/a5: MR2.5 (R4), uB2.13 (I1b), uC4.35 (A_{5})
/a6: MR2.8 (R7), uB2.15 (I2b), uC4.36 (A_{6})
/a7: MR2.3 (R2), uB2.17 (I3b), uC4.37 (A_{7})
/a8: MR1.3 (R2), uC2.17 (I3b), uC4.38 (A_{8})
/a9: MR1.8 (R7), uC2.15 (I2b), uC4.39 (A_{9})
/a10: MR1.5 (R4), uC2.13 (I1b), uC4.40 (A_{10})
/a11: MR1.2 (R1), uC2.2 (I0a), uC4.1 (A_{11})
/a12: MR1.9 (R8), uC2.4 (I1a), uC4.2 (A_{12})
/a13: MR1.4 (R3), uC2.6 (I2a), uC4.3 (A_{13})
/a14: MR1.7 (R6), uC2.8 (I3a), uC4.4 (A_{14})
/a15: MR1.6 (R5), uC2.11 (I0b), uC4.5 (A_{15})
/a~ERR: uA4.11 (C), uD7.2
/b~MREQ: uA1.12, uB1.5, uB1.10, uB1.13
/d0: MR4.8 (R7), uC4.14 (D_{0}), uC7.8 (A6)
/d1: MR4.9 (R8), uC4.15 (D_{1}), uC7.9 (A7)
/d2: MR4.6 (R5), uC4.12 (D_{2}), uC7.6 (A4)
/d3: MR4.3 (R2), uC4.8 (D_{3}), uC7.3 (A1)
/d4: MR4.2 (R1), uC4.7 (D_{4}), uC7.2 (A0)
/d5: MR4.4 (R3), uC4.9 (D_{5}), uC7.4 (A2)
/d6: MR4.5 (R4), uC4.10 (D_{6}), uC7.5 (A3)
/d7: MR4.7 (R6), uC4.13 (D_{7}), uC7.7 (A5)
/en1: uF7.1, uF8.15 (O0)
/en2: uF7.13, uF8.14 (O1)
/en3: uF8.13 (O2)
/en4: uF7.11, uF8.12 (O3)
/en5: uF7.5, uF8.11 (O4)
/en6: uF7.9, uF8.10 (O5)
/en7: uE7.13, uF8.9 (O6)
/exCp: uA8.11 (Cp), uD7.6
/ext~RESET: C1.1, CON2.1, D1.2 (A), R1.2, uB7.12, uB7.13
/ieeeD0: CON1.17, P1.2, uA6.18 (D7)
/ieeeD1: CON1.15, P1.3, uA6.17 (D6)
/ieeeD2: CON1.13, P1.4, uA6.14 (D5)
/ieeeD3: CON1.11, P1.5, uA6.13 (D4)
/ieeeD4: CON1.9, P1.6, uA6.8 (D3)
/ieeeD5: CON1.7, P1.7, uA6.7 (D2)
/ieeeD6: CON1.5, P1.8, uA6.4 (D1)
/ieeeD7: CON1.3, P1.9, uA6.3 (D0)
/pBusy: uA4.5 (Q), uA5.5
/p~ACK: uA4.4 (~S), uA5.1, uD8.14 (O1)
/p~ERR: uA4.8 (~Q), uA5.3
/~ACK: CON1.19, P1.10, uA5.12
/~BUSACK: MR5.5 (R4), uC4.23 (~BUSACK)
/~BUSREQ: MR5.7 (R6), uC4.25 (~BUSREQ)
/~CSd1: uC1.11 (O1), uD1.18 (~CS)
/~CSd3: uC1.12 (O0), uD3.18 (~CS)
/~CSd4: uC1.5 (O1), uD4.18 (~E)
/~CSd6: uC1.4 (O0), uD6.18 (~E)
/~ERR: CON1.18, uA5.10
/~HALT: MR5.4 (R3), uC4.18 (~HALT)
/~INT: MR5.2 (R1), uC4.16 (~INT)
/~IORQ: MR3.3 (R2), uA1.11, uC4.20 (~IORQ)
/~LElpt: uA1.5, uA2.13, uA4.6 (~Q), uB8.9
/~M1: MR5.8 (R7), uC4.27 (~M1)
/~MREQ: MR3.2 (R1), uA1.13, uC4.19 (~MREQ)
/~NMI: MR5.3 (R2), uC4.17 (~NMI)
/~OE: uB1.8, uD1.20 (~OE), uD3.20 (~OE), uD4.20 (~GVPP), uD6.20 (~GVPP)
/~OElpt: uA6.1 (OE), uC8.15 (O0)
/~RD: MR3.4 (R3), uA1.3, uC4.21 (~RD), uC7.1 (A->B)
/~RESET: uA4.1 (~R), uA4.13 (~R), uB7.8, uC4.26 (~RESET)
/~RFSH: MR5.9 (R8), uC4.28 (~RFSH)
/~STROBE: C6.1, CON1.1, P1.1, R13.2, uA4.3 (C)
/~WAIT: MR5.6 (R5), uC4.24 (~WAIT)
/~WE: uB1.6, uD1.21 (~WE), uD3.21 (~WE)
/~WR: MR3.5 (R4), uA1.1, uC4.22 (~WR)
/~enIN: uC8.9 (O6), uE8.1 (E1)
D0: uA6.19 (O7), uA8.18 (D7), uB8.8, uB8.11, uC7.12 (B6), uD1.9 (I/O1), uD3.9 (I/O1), uD4.9 (Q0), uD6.9 (Q0), uE7.3, uE8.13 (O6)
D1: uA6.16 (O6), uA8.17 (D6), uC7.11 (B7), uD1.10 (I/O2), uD3.10 (I/O2), uD4.10 (Q1), uD6.10 (Q1), uE7.11
D2: uA6.15 (O5), uA8.14 (D5), uC7.14 (B4), uD1.11 (I/O3), uD3.11 (I/O3), uD4.11 (Q2), uD6.11 (Q2), uE7.5, uE8.11 (O5)
D3: uA6.12 (O4), uA8.13 (D4), uC7.17 (B1), uD1.13 (I/O4), uD3.13 (I/O4), uD4.13 (Q3), uD6.13 (Q3), uE7.9, uE8.7 (O3)
D4: uA6.9 (O3), uA8.8 (D3), uC7.18 (B0), uD1.14 (I/O5), uD3.14 (I/O5), uD4.14 (Q4), uD6.14 (Q4), uF8.1 (A0)
D5: uA6.6 (O2), uA8.7 (D2), uC7.16 (B2), uD1.15 (I/O6), uD3.15 (I/O6), uD4.15 (Q5), uD6.15 (Q5), uE8.5 (O2), uF8.2 (A1)
D6: uA6.5 (O1), uA8.4 (D1), uC7.15 (B3), uD1.16 (I/O7), uD3.16 (I/O7), uD4.16 (Q6), uD6.16 (Q6), uE8.9 (O4), uF8.3 (A2)
ENdrv: uD7.4, uF8.6 (E3)
GND: C0.2, C1.2, C3.2, C4.2, C5.2, C6.2, C7.2, C8.2, C9.2, C10.2, C11.2, C12.2, C13.2, C14.2, C15.2, C16.2, C17.2, C18.2, C19.2, C20.2, C21.2, C22.2, C23.2, C24.2, C25.2, C26.2, C27.2, C28.2, C29.2, C30.2, C31.2, C32.2, C33.2, C34.2, C35.2, C36.2, C37.2, C38.2, CON1.2, CON1.4, CON1.6, CON1.8, CON1.10, CON1.12, CON1.14, CON1.16, CON2.2, CON2.4, CON2.6, CON3.9, CON3.10, CON4.5, CON4.6, CON5.2, CON6.2, CON7.2, CON8.2, CON9.2, CON10.2, CON11.2, CON12.1, CON13.3, CON13.4, JP1.1 (A), P1.18, P1.19, P1.20, P1.21, P1.22, P1.23, P1.24, P1.25, R4.2, Y1.3, fE5.12 (GND), fE6.12 (GND), uA1.7 (GND), uA2.7 (GND), uA4.2 (D), uA4.7 (GND), uA5.7 (GND), uA6.10 (GND), uA8.10 (GND), uB1.7 (GND), uB2.1 (OEa), uB2.10 (GND), uB2.19 (OEb), uB7.7 (GND), uB8.7 (GND), uC1.8 (GND), uC2.1 (OEa), uC2.10 (GND), uC2.19 (OEb), uC4.29 (GND), uC7.10 (GND), uC7.19 (CE), uC8.8 (GND), uD1.12 (GND), uD3.12 (GND), uD4.12 (GND), uD6.12 (GND), uD7.7 (GND), uD8.8 (GND), uE1.12 (GND), uE2.12 (GND), uE3.12 (GND), uE4.12 (GND), uE7.7 (GND), uE8.8 (GND), uE8.15 (E2), uF0.12 (GND), uF1.4 (GND), uF1.5 (GND), uF1.12 (GND), uF1.13 (GND), uF2.4 (GND), uF2.5 (GND), uF2.12 (GND), uF2.13 (GND), uF3.4 (GND), uF3.5 (GND), uF3.12 (GND), uF3.13 (GND), uF4.4 (GND), uF4.5 (GND), uF4.12 (GND), uF4.13 (GND), uF5.4 (GND), uF5.5 (GND), uF5.12 (GND), uF5.13 (GND), uF6.4 (GND), uF6.5 (GND), uF6.12 (GND), uF6.13 (GND), uF7.7 (GND), uF8.4 (E1), uF8.5 (E2), uF8.8 (GND)
unnamed: C2.1, Y1.2
unnamed: C2.2, C4.1, R3.2, uB7.3, uB7.4, uB7.5
unnamed: C3.1, R3.1, R4.1, Y1.1, uB7.1, uB7.2
unnamed: C5.1, R12.2, uA2.12
unnamed: CON2.5, R10.1
unnamed: CON3.1, uA8.19 (Q7)
unnamed: CON3.2, uA8.16 (Q6)
unnamed: CON3.3, uA8.15 (Q5)
unnamed: CON3.4, uA8.12 (Q4)
unnamed: CON3.5, uA8.9 (Q3)
unnamed: CON3.6, uA8.6 (Q2)
unnamed: CON3.7, uA8.5 (Q1)
unnamed: CON3.8, uA8.2 (Q0)
unnamed: CON4.1, uF0.1 (~Q0)
unnamed: CON4.2, uF0.14 (~Q1)
unnamed: CON4.3, uF0.11 (~Q2)
unnamed: CON4.4, uF0.8 (~Q3)
unnamed: CON5.1, MR6.4 (R3), uE8.14 (I6)
unnamed: CON6.1, MR6.6 (R5), uE8.12 (I5)
unnamed: CON7.1, MR6.8 (R7), uE8.10 (I4)
unnamed: CON8.1, MR6.7 (R6), uE8.6 (I3)
unnamed: CON9.1, MR6.5 (R4), uE8.4 (I2)
unnamed: CON10.1, MR6.3 (R2), uE8.2 (I1)
unnamed: CON11.1, R24.1
unnamed: CON12.2, JP1.2 (B), R7.2, uB8.2
unnamed: D2.1 (K), uF1.1 (COM), uF1.8 (COM)
unnamed: D3.1 (K), uF2.1 (COM), uF2.8 (COM)
unnamed: D4.1 (K), uF3.1 (COM), uF3.8 (COM)
unnamed: D5.1 (K), uF4.1 (COM), uF4.8 (COM)
unnamed: D6.1 (K), uF5.1 (COM), uF5.8 (COM)
unnamed: D7.1 (K), uF6.1 (COM), uF6.8 (COM)
unnamed: M1.1, uF1.2 (O1)
unnamed: M1.2, uF1.7 (O2)
unnamed: M1.3, uF1.9 (O3)
unnamed: M1.4, uF1.16 (O4)
unnamed: M2.1, uF2.2 (O1)
unnamed: M2.2, uF2.7 (O2)
unnamed: M2.3, uF2.9 (O3)
unnamed: M2.4, uF2.16 (O4)
unnamed: M3.1, uF3.2 (O1)
unnamed: M3.2, uF3.7 (O2)
unnamed: M3.3, uF3.9 (O3)
unnamed: M3.4, uF3.16 (O4)
unnamed: M4.1, uF4.2 (O1)
unnamed: M4.2, uF4.7 (O2)
unnamed: M4.3, uF4.9 (O3)
unnamed: M4.4, uF4.16 (O4)
unnamed: M5.1, uF5.2 (O1)
unnamed: M5.2, uF5.7 (O2)
unnamed: M5.3, uF5.9 (O3)
unnamed: M5.4, uF5.16 (O4)
unnamed: M6.1, uF6.2 (O1)
unnamed: M6.2, uF6.7 (O2)
unnamed: M6.3, uF6.9 (O3)
unnamed: M6.4, uF6.16 (O4)
unnamed: Q1.3 (B), R11.1, R23.2
unnamed: Q1.2 (C), R10.2
unnamed: R12.1, uA1.6
unnamed: R23.1, uD7.12
unnamed: fE5.2 (D0), fE6.2 (D0), uE1.2 (D0), uE2.2 (D0), uE3.2 (D0), uE4.2 (D0), uE7.8, uF0.2 (D0)
unnamed: fE5.3 (D1), fE6.3 (D1), uE1.3 (D1), uE2.3 (D1), uE3.3 (D1), uE4.3 (D1), uE7.6, uF0.3 (D1)
unnamed: fE5.6 (D2), fE6.6 (D2), uE1.6 (D2), uE2.6 (D2), uE3.6 (D2), uE4.6 (D2), uE7.10, uF0.6 (D2)
unnamed: fE5.7 (D3), fE6.7 (D3), uE1.7 (D3), uE2.7 (D3), uE3.7 (D3), uE4.7 (D3), uE7.4, uF0.7 (D3)
unnamed: fE5.4 (E23), fE5.13 (E01), uF7.6
unnamed: fE5.1 (~Q0), uF5.3 (I1)
unnamed: fE5.14 (~Q1), uF5.6 (I2)
unnamed: fE5.11 (~Q2), uF5.11 (I3)
unnamed: fE5.8 (~Q3), uF5.14 (I4)
unnamed: fE6.4 (E23), fE6.13 (E01), uF7.8
unnamed: fE6.1 (~Q0), uF6.3 (I1)
unnamed: fE6.14 (~Q1), uF6.6 (I2)
unnamed: fE6.11 (~Q2), uF6.11 (I3)
unnamed: fE6.8 (~Q3), uF6.14 (I4)
unnamed: uA1.2, uA2.4, uB1.4
unnamed: uA1.4, uA2.9, uB1.9
unnamed: uA1.10, uA2.5, uA2.10
unnamed: uA2.11, uD7.9
unnamed: uA4.9 (Q), uD7.13
unnamed: R14.2, uA4.10 (~S)
unnamed: uA5.4, uA5.11
unnamed: uA5.2, uA5.13
unnamed: uA6.11 (LE), uD7.8
unnamed: R5.2, uA8.1 (~Mr)
unnamed: uB7.9, uB7.10, uB7.11
unnamed: R2.2, uB7.6, uC4.6 (CLK)
unnamed: R6.2, uC8.6 (E3)
unnamed: uB8.10, uC8.13 (O2)
unnamed: uB8.13, uC8.11 (O4)
unnamed: uB8.1, uC8.10 (O5)
unnamed: R8.2, uD8.6 (E3)
unnamed: uD7.5, uD8.12 (O3)
unnamed: uD7.1, uD8.10 (O5)
unnamed: uD7.3, uD8.7 (O7)
unnamed: uE1.4 (E23), uE1.13 (E01), uF7.2
unnamed: uE1.1 (~Q0), uF1.3 (I1)
unnamed: uE1.14 (~Q1), uF1.6 (I2)
unnamed: uE1.11 (~Q2), uF1.11 (I3)
unnamed: uE1.8 (~Q3), uF1.14 (I4)
unnamed: uE2.4 (E23), uE2.13 (E01), uF7.12
unnamed: uE2.1 (~Q0), uF2.3 (I1)
unnamed: uE2.14 (~Q1), uF2.6 (I2)
unnamed: uE2.11 (~Q2), uF2.11 (I3)
unnamed: uE2.8 (~Q3), uF2.14 (I4)
unnamed: uE3.4 (E23), uE3.13 (E01), uF7.4
unnamed: uE3.1 (~Q0), uF3.3 (I1)
unnamed: uE3.14 (~Q1), uF3.6 (I2)
unnamed: uE3.11 (~Q2), uF3.11 (I3)
unnamed: uE3.8 (~Q3), uF3.14 (I4)
unnamed: uE4.4 (E23), uE4.13 (E01), uF7.10
unnamed: uE4.1 (~Q0), uF4.3 (I1)
unnamed: uE4.14 (~Q1), uF4.6 (I2)
unnamed: uE4.11 (~Q2), uF4.11 (I3)
unnamed: uE4.8 (~Q3), uF4.14 (I4)
unnamed: uE7.12, uF0.4 (E23), uF0.13 (E01)

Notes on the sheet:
uD8
uC8
uE6
uD3
uD1
uD6
uF8
uF0
uA6
uC7
uE5
uE8
uD4
uC2
uE1
uB2
uE2
uC4
uE3
uE4
uA8

Board: 2 copper layers, 142 parts (0 on the bottom side), 216 nets, no tracks yet.

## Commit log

2026-04-21 Primera version del esquema
    [71922-120LF.step, Molex_KK-396_26605050_1x05_P3.96mm_Horizontal.step, dt-001.kicad_pcb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]
2026-04-21 Agregando fotos de referencia
2026-04-21 agregando caracteristica de circuito sch, control de motores
2026-04-21 agregando imagen con mod cable DB9
2026-04-27 actualizacion a KiCad 10
    [dt-001.kicad_pcb, dt-001.kicad_sch]
2026-05-07 agregango panel y archivos para construccion
    [DSUB-9_Pins_Vertical_P2.77x2.84mm.step, addon_db9.FCStd, dt-001.kicad_pcb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]
2026-10-17 Add license and KiCad badges to README
    Added badges for MIT License and KiCad in README.

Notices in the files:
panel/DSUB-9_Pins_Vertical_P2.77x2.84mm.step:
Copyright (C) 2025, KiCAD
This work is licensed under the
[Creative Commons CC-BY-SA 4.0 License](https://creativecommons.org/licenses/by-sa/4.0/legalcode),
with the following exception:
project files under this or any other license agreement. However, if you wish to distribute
